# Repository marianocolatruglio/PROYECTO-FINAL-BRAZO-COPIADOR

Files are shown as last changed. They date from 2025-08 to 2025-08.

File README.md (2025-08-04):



# Sistema de Digitalizacion y Reproduccion de Contornos
Desarrollado por Colatruglio M. - Dziubek N.
## Introduccion

La evolución tecnológica en el ámbito industrial ha llevado a una creciente necesidad de soluciones automatizadas que permitan a pequeñas y medianas empresas mejorar su competitividad. En particular, el desarrollo de herramientas capaces de reproducir trayectorias manuales con precisión resulta de gran interés para sectores como la metalurgia, carpintería o manufactura personalizada.
La automatización industrial ha impulsado el desarrollo de dispositivos capaces de ejecutar tareas con precisión creciente. En este contexto, los brazos articulados han demostrado ser herramientas fundamentales para reproducir trayectorias definidas, tanto en entornos remotos como en talleres locales.
Este tipo de tecnología también resulta útil en talleres metalúrgicos de pequeña escala, donde un operario puede escanear una pieza irregular guiando manualmente el brazo y luego reproducir la misma trayectoria para realizar cortes sobre placas de metal. Esto permite fabricar tanto piezas únicas como series reducidas de forma eficiente.
Frente a la necesidad de una alternativa nacional y de bajo costo a los sistemas importados, se desarrolló un prototipo funcional que demuestra la viabilidad técnica de capturar y reproducir trayectorias con buena precisión, empleando componentes accesibles como Arduino y piezas impresas en 3D.
El proyecto consistió en desarrollar un brazo articulado de dos grados de libertad, capaz de grabar trayectorias guiadas por el usuario y luego reproducirlas automáticamente. Este tipo de soluciones se observa en la industria metalúrgica internacional, especialmente en tareas de corte térmico.
Se planteó una alternativa local escalable, partiendo de un prototipo a pequeña escala como prueba de concepto. Si bien este no incluye herramientas de corte reales, sí valida el sistema de guiado, almacenamiento y reproducción.

RENDER1

# Objetivo
* Proveer a la industria de un sistema de posicionamiento robotico para operaciones de corte de metales in-situ de bajo costo , modular y de facil operacion, utilizando una estructura abierta.
* Sustituir equipos importados de alto costo.

# Principio de Funcionamiento 

Se seleccionó como accionamiento 2 motores paso a paso, por su simplicidad y presición de posicionamiento, utilizando una configuracion de multistepping 1/16. Ademas se agregaron encoders magneticos AS5600 que tienen una 
precision de 4096 steps/rev. Estos se utilizaran para obtener la posicion angular de los brazos. Con esta informacion crearemos un streaming de datos se transmitirá via serial mediante pares de coordenadas que se almacenaran en un archivo .TXT a traves de un script de Python. 

## Arduino UNO 

## Resumen del funcionamiento

Este código controla un **brazo copiador** con dos motores paso a paso y encoders magnéticos **AS5600** (lectura multivuelta). Los puntos más relevantes:

1. **Lectura de encoders (AS5600):**

   * Se obtienen ángulos absolutos en crudo (RAW ANGLE) a través de I²C.
   * Se implementa un contador manual de vueltas para cada encoder usando un multiplexor 4051.

2. **Control de motores:**

   * Los motores paso a paso se manejan mediante drivers tipo A4988/TMC, con microstepping configurado a **1/8** (1600 pasos/rev, 0.225°/paso).
   * Se implementa un **movimiento interpolado** con velocidad constante de **45°/s**, ajustable con `speedFactor`.
   * Al finalizar un segmento, se aplica **corrección de posición** usando el feedback de los encoders (anti-drift).

3. **Homing automático:**

   * Rutina `homingSimultaneo()` para buscar finales de carrera, retroceder y re-inicializar el conteo de ángulos.

4. **Grabación y reproducción de trayectorias:**

   * **Grabación:** lee continuamente los ángulos de los encoders y los envía por puerto serie (`g`).
   * **Reproducción:** recibe una secuencia de ángulos (`INICIO_TRAYECTORIA` ... `FIN_TRAYECTORIA`) por serie y ejecuta los movimientos de forma sincronizada (`r`).
   * Comunicación con **handshake**: el Arduino responde con `RDY`, `OK` por cada segmento y `DONE` al finalizar.

5. **Comandos por serie:**

   * `h`: homing
   * `g`: iniciar grabación
   * `r`: reproducir trayectoria
   * `x`: detener grabación
   * `p`: imprimir posición actual
   * `e` / `d`: habilitar o deshabilitar drivers

6. **GUI - INTERFAZ GRAFICA**
   
   

8. **Detalles técnicos:**

   * Corrección de errores por redondeo en pasos mediante acumulación de restos.
   * Tiempo por paso calculado dinámicamente para mantener la velocidad angular deseada.
   * Tolerancia de corrección final de \~0.1° (medio micropaso).

## Morfologia del robot.
  Se utilizo una configuracion de brazos planos paralelos con ambos accionamientos sobre el mismo eje.
  Esto se decidió con el objetivo de reducir el peso en el extremo del robot, con el ojetivo de alcanzar extensiones largas con una inercia minima.
  La reduccion de los motores es de 88/16, mediante correas GT2, las cuales se imprimieron en 3D con filamento flexible TPU.
  De esta forma se agrupo toda la transmision en la base del dispositivo donde se concentra la mayor parte del peso.

## Encoders AS5600

Estos encoders utilizan una comunicacion I2C, con el problema que tienen una direccion estatica 0x36. lo cual nos obligo a utilizar un multiplexor, segun recomendacion del creador de la Libreria (https://github.com/RobTillaart/AS5600) utilizamos el siguiente : CD74HC4067. De esta forma podemos obtener datos de ambos encoders simultaneamente.

## CNC Shield Protoneer v3.0

La placa de expansión para máquina de grabado CNC Shield V3 de Protoneer es una placa de expansión versátil y potente diseñada para controlar motores paso a paso en máquinas CNC. Se utiliza comúnmente en routers CNC, cortadoras láser y máquinas de grabado DIY. La placa es compatible con Arduino UNO y utiliza firmware GRBL para controlar hasta cuatro motores paso a paso, lo que permite un funcionamiento preciso y eficiente de la máquina.
En nuestro proyecto la utilizamos con una configuracion personalizada para utilizar los pines disponibles para conectar los encoders, el multiplexor y los fines de carrera.

## Homing

Es necesario darle un origen de referencia al sistema, para inicializar la posicion, entonces se debio programar una rutina de homing. Utilizamos 2 microswitchs para ello, los cuales se accionan al llevar los brazos al origen.

# Componentes del Sistema 

### 🔹 Motor Paso a Paso NEMA 23

* **Descripción**: Motor paso a paso de alto torque utilizado para el control preciso de los ejes en máquinas CNC.
---

### 🔹 Placa de Expansión CNC Shield V3 para Grabado

* **Descripción**: Placa de expansión que se conecta al Arduino para controlar motores paso a paso y otros periféricos.
---

### 🔹 Fuente de Alimentación

* **Descripción**: Proporciona energía eléctrica a la CNC Shield y los componentes conectados.
---

### 🔹 Driver A4988

* **Descripción**: Controlador para motores paso a paso, utilizado para manejar los motores NEMA 23.
---

### 🔹 Arduino UNO

* **Descripción**: Microcontrolador principal que gestiona la lógica de control de la máquina CNC.
---

### 🔹 Sensor AS5600

* **Descripción**: Sensor magnético de posición rotativa, utilizado como realimentación tipo encoder.
---

### 🔹 Multiplexor CD74HC4067

* **Descripción**: Multiplexor/demultiplexor analógico de 16 canales.
---

### 🔹 Finales de Carrera (Limit Switch)

* **Descripción**: Detectan el fin de recorrido de los ejes del sistema CNC.
---

# Circuitos
circuit_image

# Fabricacion del prototipo

Para la fabricacion del prototipo utilizamos el software de modelado parametrico Solidworks, donde se modelaron integramente las piezas mecanicas, para luego ser impresas mediante el proceso de FDM.
Se utilizó una impresora Anycubic Kobra Neo 2 y las piezas se imprimieron con filamento PLA. Las correas GT2 se imprimieron con filamente FLEX - TPU.

# Prueba - VIDEO

https://github.com/user-attachments/assets/5a15703d-f460-4125-8f47-778ed20e3b36

# Despiece - VIDEO

https://github.com/user-attachments/assets/c534c029-4edf-490a-99b5-7e7f0a055c2a

# Vistas del Modelo

<p align="center">
  
</p>

<p align="center">
  
</p>

<p align="center">
  
</p>

# 🗓️ Cronograma Mensual del Proyecto Final (Marzo–Julio 2025)

| Mes | Investigación (h) | Aplicación (h) | Programación (h) | Total mensual (h) | Actividades principales |
|---|---|---|---|---|---|
| March 2025 | 1.6 | 4.7 | 4.2 | 10.5 | Inicio del proyecto, selección de plataforma, motores y encoders AS5600 |
| April 2025 | 1.1 | 3.4 | 3.0 | 7.5 | Implementación multiplexor, pruebas PWM/I2C, brazo paralelo plano |
| May 2025 | 1.1 | 3.4 | 3.0 | 7.5 | Homing, control lazo cerrado, sincronización motores |
| June 2025 | 1.1 | 3.4 | 3.0 | 7.5 | Grabación de trayectorias, visualización en Python, debugging |
| July 2025 | 3.4 | 10.1 | 9.0 | 22.5 | Validación de cinemática , pruebas finales, afinación |

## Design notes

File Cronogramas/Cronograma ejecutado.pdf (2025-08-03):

Proyecto Final | Leyenda:

## Colatruglio - Dziubek

Fecha de inicio del proyecto: | 7/4/2025 | abril | mayo | junio
7 | 8 | 9 | 10 | 11 | 12 | 13 | 14 | 15 | 16 | 17 | 18 | 19 | 20 | 21 | 22 | 23 | 24 | 25 | 26 | 27 | 28 | 29 | 30 | 1 | 2 | 3 | 4 | 5 | 6 | 7 | 8 | 9 | 10 | 11 | 12 | 13 | 14 | 15 | 16 | 17 | 18 | 19 | 20 | 21 | 22 | 23 | 24 | 25 | 26 | 27 | 28 | 29 | 30 | 31 | 1 | 2 | 3 | 4 | 5 | 6 | 7 | 8 | 9 | 10 | 11
Nº Act Descripción del hito | Categoría | Asignado a | Dependencia | Inicio | Días | l | m | m | j | v | s | d | l | m | m | j | v | s | d | l | m | m | j | v | s | d | l | m | m | j | v | s | d | l | m | m | j | v | s | d | l | m | m | j | v | s | d | l | m | m | j | v | s | d | l | m | m | j | v | s | d | l | m | m | j | v | s | d | l | m | m
1 | Modelado | Según lo previsto | Colatruglio - Dziubek | - | 7/4/2025 | 2
2 | Definición de Requerimientos | Riesgo medio | Colatruglio - Dziubek | - | 7/4/2025 | 2
3 | Definición de Lenguaje | Según lo previsto | Colatruglio - Dziubek | 2 | 9/4/2025 | 3
4 | Selección de periféricos | Riesgo medio | Colatruglio | 3 | 10/4/2025 | 4
5 | Dimensionamiento | Riesgo bajo | Colatruglio - Dziubek | 1 | 10/4/2025 | 5
6 | Gestion de Compras | Riesgo medio | Colatruglio - Dziubek | 4 | 15/4/2025 | 2
7 | Prefabricación | Según lo previsto | Colatruglio | 4 y 5 | 15/4/2025 | 4
8 | Fabricación | Según lo previsto | Colatruglio - Dziubek | 6 | 22/4/2025 | 7
9 | T. Levantamiento de Datos | Hito | Dziubek | 6 | 22/4/2025 | 1
10 | T. Giro de Motores | Riesgo medio | Colatruglio | 6 | 22/4/2025 | 4
11 | Comunicación de Periféricos | Según lo previsto | Colatruglio - Dziubek | 7 | 29/4/2025 | 4
12 | Levantamiento de Datos | Riesgo alto | Colatruglio - Dziubek | 11 | 1/5/2025 | 4
13 | T. Comunicación de periféricos | Hito | Colatruglio | 11 | 1/5/2025 | 1
14 | T. Modelo | Riesgo bajo | Dziubek | 8 y 11 | 1/5/2025 | 5

15

Desarrollo lógico de trayectorias | Riesgo medio | Colatruglio - Dziubek | 12 | 6/5/2025 | 10

16

T. Parametrización de la
información | Según lo previsto | Dziubek | 12 | 6/5/2025 | 2
17 | T. Lectura de los Sensores | Hito | Colatruglio | 12 | 6/5/2025 | 1
18 | Testeo | Riesgo alto | Colatruglio - Dziubek | 14 y 15 | 13/5/2025 | 29
19 | Corrección de errores | Según lo previsto | Colatruglio - Dziubek | 18 | 6/6/2025 | 5
20 | Puesta en Marcha | Hito | Colatruglio - Dziubek | 19 | 11/6/2025 | 1
Riesgo alto | Sin asignar

# Sistema de Digitalizacion y Reproduccion de Contornos

Según lo previsto | Riesgo bajo | Riesgo medio

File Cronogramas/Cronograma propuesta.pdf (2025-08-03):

Proyecto Final | Leyenda:

## Colatruglio - Dziubek

Fecha de inicio del proyecto: 7/4/2025 | abril | mayo | junio
7 | 8 | 9 | 10 | 11 | 12 | 13 | 14 | 15 | 16 | 17 | 18 | 19 | 20 | 21 | 22 | 23 | 24 | 25 | 26 | 27 | 28 | 29 | 30 | 1 | 2 | 3 | 4 | 5 | 6 | 7 | 8 | 9 | 10 | 11 | 12 | 13 | 14 | 15 | 16 | 17 | 18 | 19 | 20 | 21 | 22 | 23 | 24 | 25 | 26 | 27 | 28 | 29 | 30 | 31 | 1 | 2 | 3 | 4 | 5 | 6 | 7 | 8 | 9 | 10 | 11
Nº Act | Descripción del hito | Categoría | Asignado a | Dependencia | Inicio | Días | l | m | m | j | v | s | d | l | m | m | j | v | s | d | l | m | m | j | v | s | d | l | m | m | j | v | s | d | l | m | m | j | v | s | d | l | m | m | j | v | s | d | l | m | m | j | v | s | d | l | m | m | j | v | s | d | l | m | m | j | v | s | d | l | m | m
1 | Modelado | Según lo previsto | Colatruglio - Dziubek | - | 7/4/2025 | 2
2 | Definición de Requerimientos | Según lo previsto | Colatruglio - Dziubek | - | 7/4/2025 | 1
3 | Definición de Lenguaje | Según lo previsto | Colatruglio - Dziubek | 2 | 9/4/2025 | 1
4 | Selección de periféricos | Según lo previsto | Colatruglio | 3 | 10/4/2025 | 4
5 | Dimensionamiento | Según lo previsto | Colatruglio - Dziubek | 1 | 10/4/2025 | 1
6 | Gestion de Compras | Según lo previsto | Colatruglio - Dziubek | 4 | 15/4/2025 | 6
7 | Prefabricación | Según lo previsto | Colatruglio | 4 y 5 | 15/4/2025 | 1
8 | Fabricación | Según lo previsto | Colatruglio - Dziubek | 6 | 22/4/2025 | 6
9 | T. Levantamiento de Datos | Hito | Dziubek | 6 | 22/4/2025 | 1
10 | T. Giro de Motores | Según lo previsto | Colatruglio | 6 | 22/4/2025 | 1
11 | Comunicación de Periféricos | Según lo previsto | Colatruglio - Dziubek | 7 | 29/4/2025 | 1
12 | Levantamiento de Datos | Según lo previsto | Colatruglio - Dziubek | 11 | 1/5/2025 | 4
13 | T. Comunicación de periféricos | Hito | Colatruglio | 11 | 1/5/2025 | 1
14 | T. Modelo | Según lo previsto | Dziubek | 8 y 11 | 1/5/2025 | 4
15 | Desarrollo lógico de trayectorias | Según lo previsto | Colatruglio - Dziubek | 12 | 6/5/2025 | 6

16

T. Parametrización de la
| información | Según lo previsto | Dziubek | 12 | 6/5/2025 | 1
17 | T. Lectura de los Sensores | Hito | Colatruglio | 12 | 6/5/2025 | 1
18 | Testeo | Según lo previsto | Colatruglio - Dziubek | 14 y 15 | 13/5/2025 | 23
19 | Corrección de errores | Según lo previsto | Colatruglio - Dziubek | 18 | 6/6/2025 | 4
20 | Puesta en Marcha | Hito | Colatruglio - Dziubek | 19 | 11/6/2025 | 1
Riesgo alto | Sin asignar

# Sistema de Digitalizacion y Reproduccion de Contornos

Según lo previsto | Riesgo bajo | Riesgo medio

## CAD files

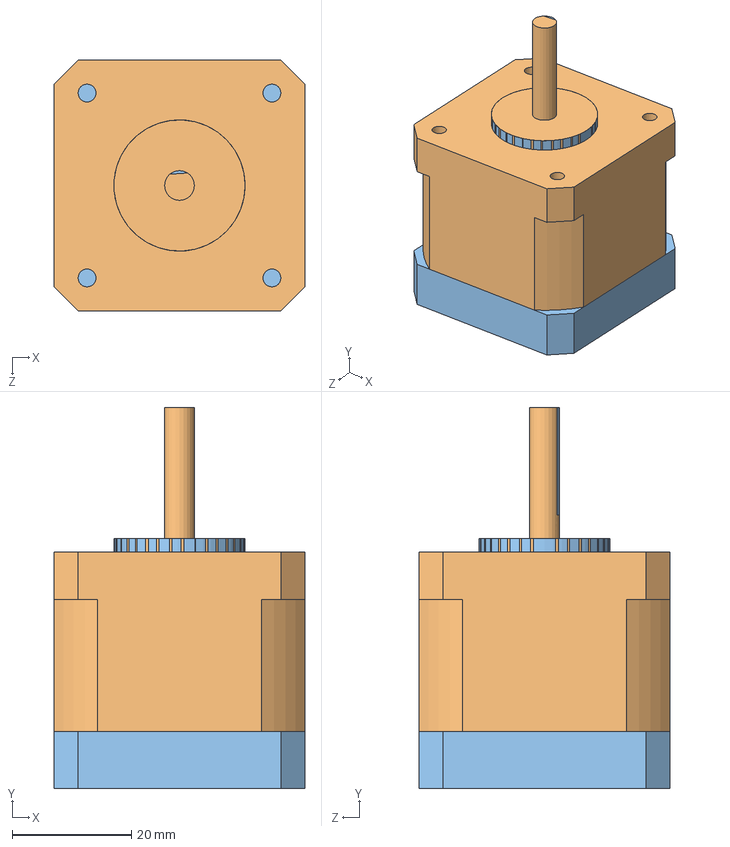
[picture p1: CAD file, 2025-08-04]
Assembly/NEMA17.SLDASM
42.0 x 63.9 x 42.0 mm

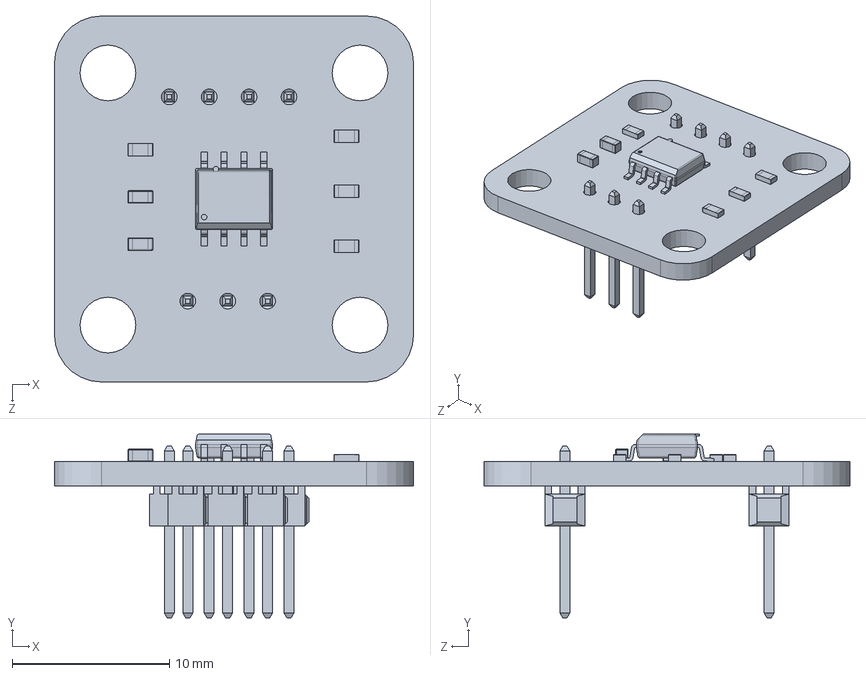
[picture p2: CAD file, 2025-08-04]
Assembly/AS5600.SLDPRT
22.9 x 11.7 x 23.3 mm

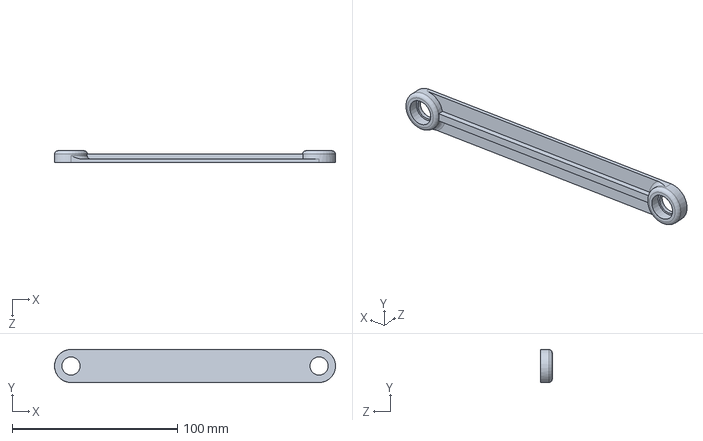
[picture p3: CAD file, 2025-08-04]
Assembly/ESLABON_3.sldprt
169.9 x 20.0 x 7.00 mm

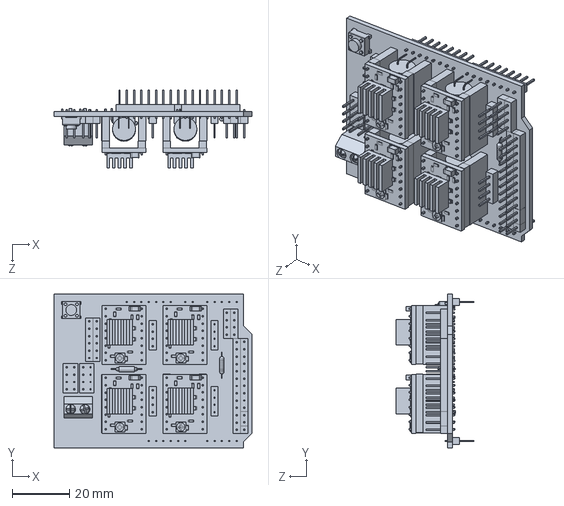
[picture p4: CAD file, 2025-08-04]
Assembly/Arduino_Uno_CNC_Shield_V3.SLDPRT
69.0 x 53.5 x 27.1 mm

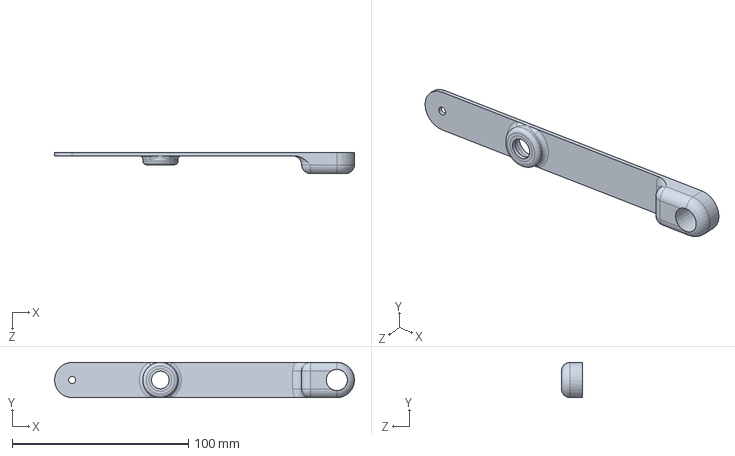
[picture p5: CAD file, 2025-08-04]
Assembly/ESLABON_4.sldprt
170.0 x 20.0 x 12.0 mm

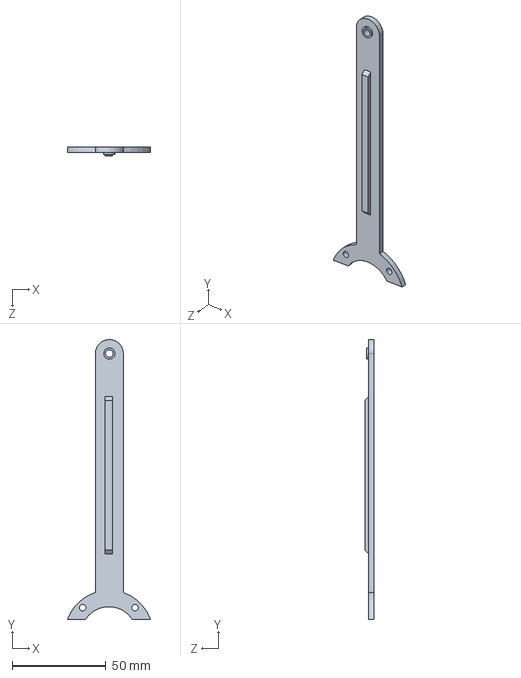
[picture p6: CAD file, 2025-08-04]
Assembly/ESLABON_1.sldprt
44.4 x 149.5 x 5.00 mm

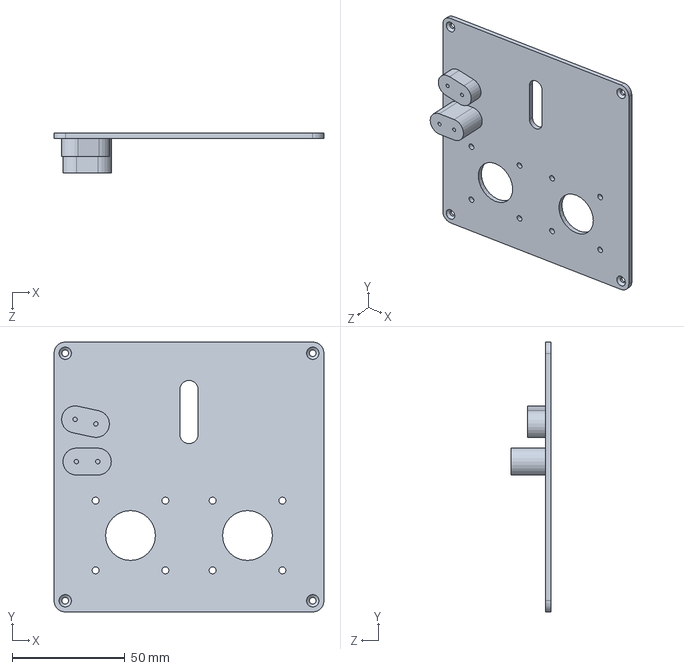
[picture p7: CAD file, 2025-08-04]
Assembly/Part5.sldprt
120.0 x 120.0 x 18.0 mm

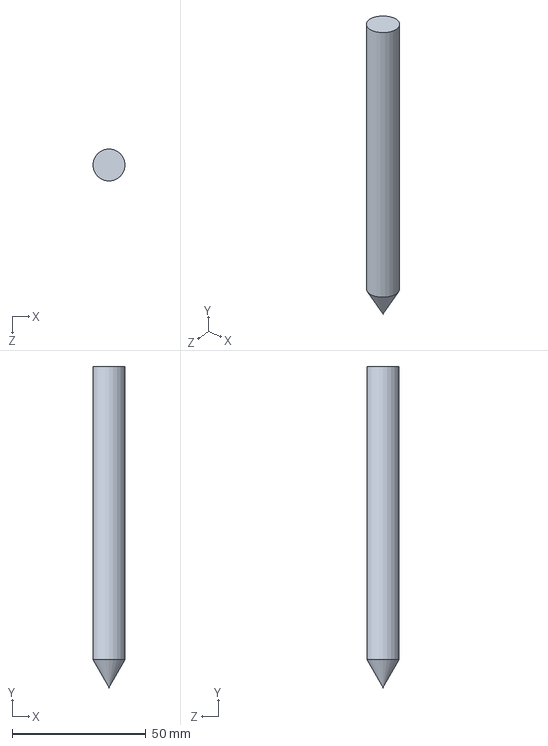
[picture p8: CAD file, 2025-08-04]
Assembly/lapiz.SLDPRT
12.0 x 120.0 x 12.0 mm

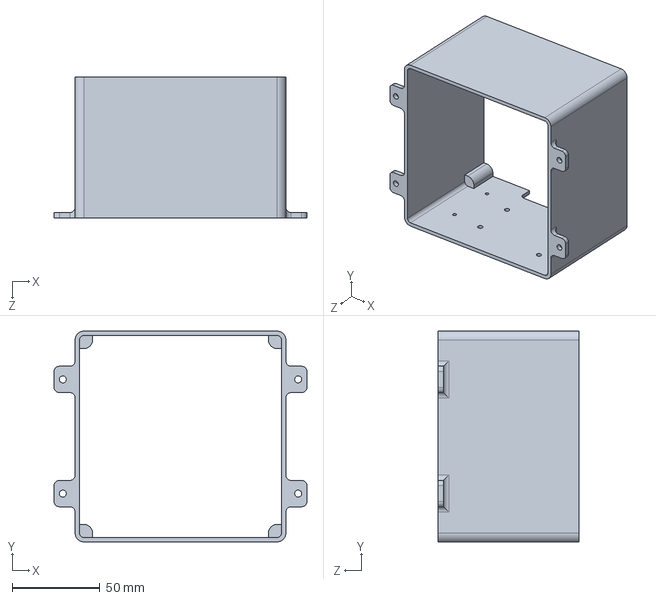
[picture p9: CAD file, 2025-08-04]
Assembly/Carcaza externa.sldprt
144.0 x 120.0 x 80.0 mm

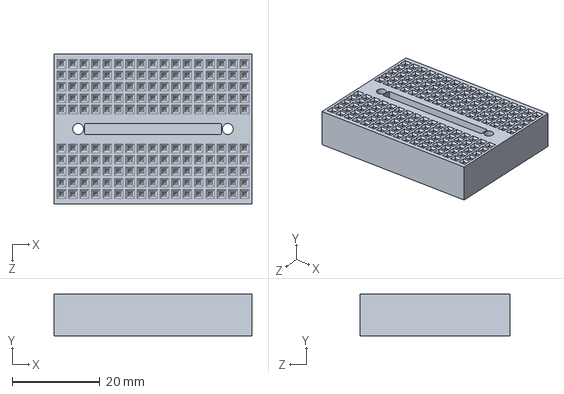
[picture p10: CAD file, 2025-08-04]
Assembly/MINIPROTOBOARD.SLDPRT
45.0 x 9.50 x 34.0 mm

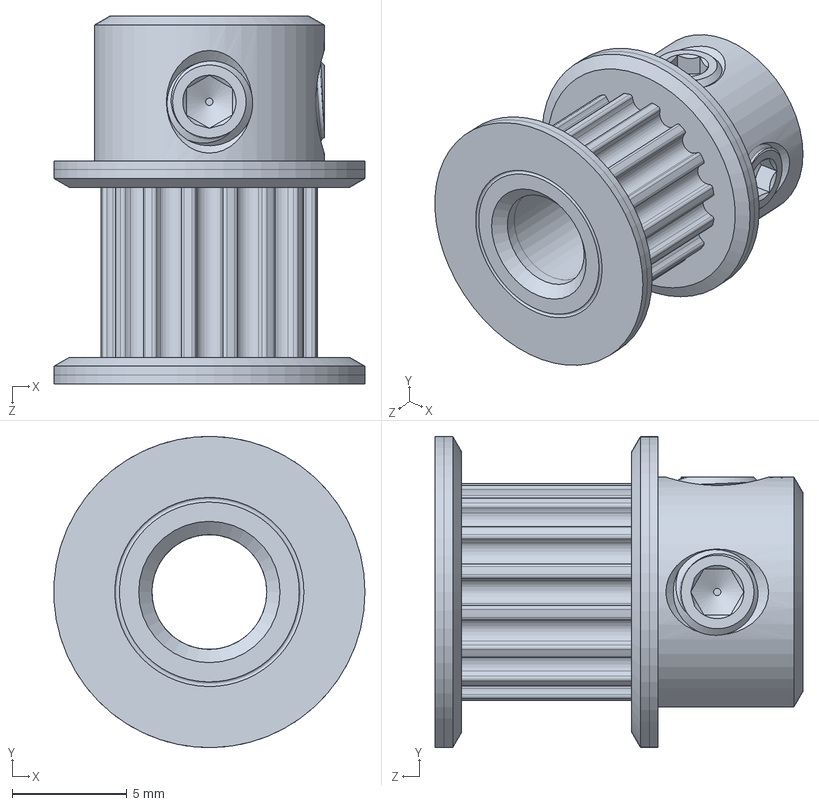
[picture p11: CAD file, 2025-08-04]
Assembly/GT2_06SWidth_16Num_5IDia_10HDia.SLDPRT
13.5 x 13.5 x 16.0 mm

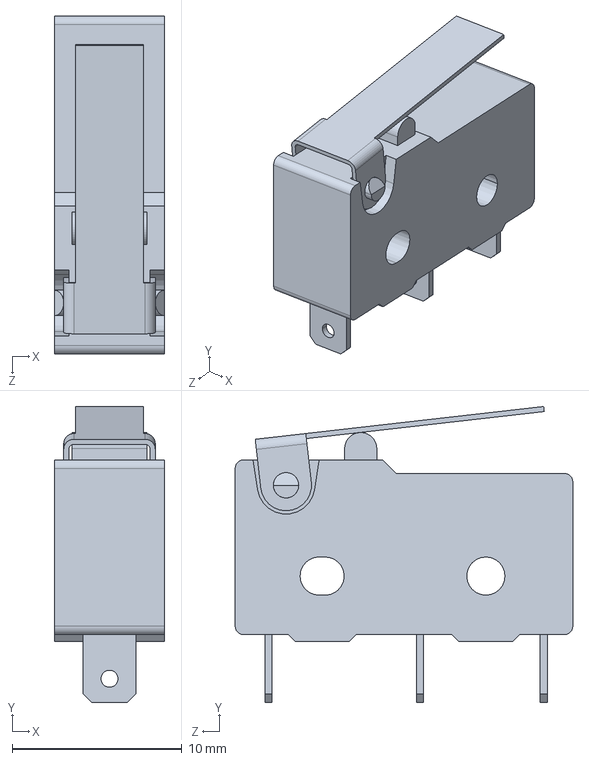
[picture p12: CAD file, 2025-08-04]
Assembly/Micro Limit Switch (Straight Lever) 605630.SLDPRT
6.50 x 17.4 x 19.9 mm

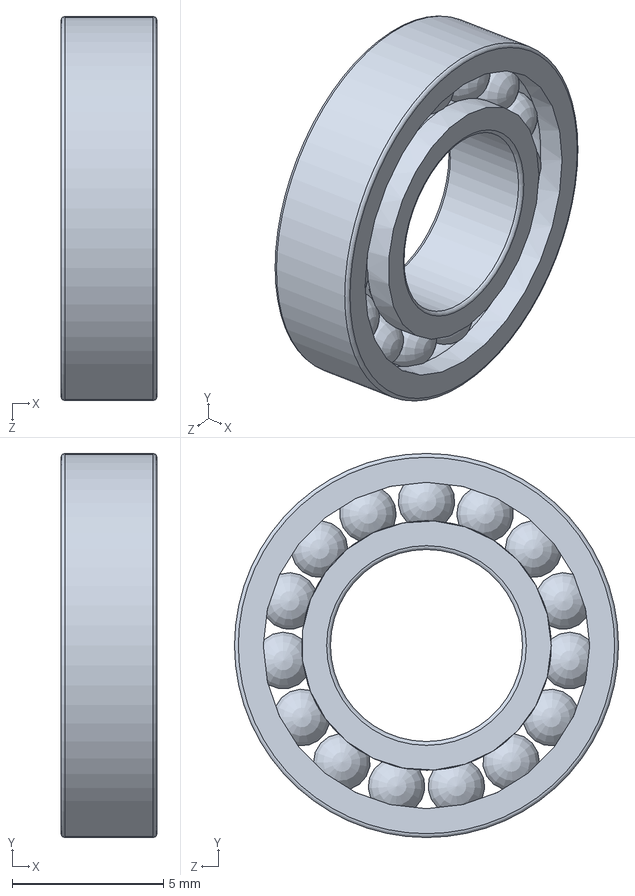
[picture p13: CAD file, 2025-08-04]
Assembly/radial ball bearing_68_skf.sldprt
3.17 x 12.7 x 12.7 mm

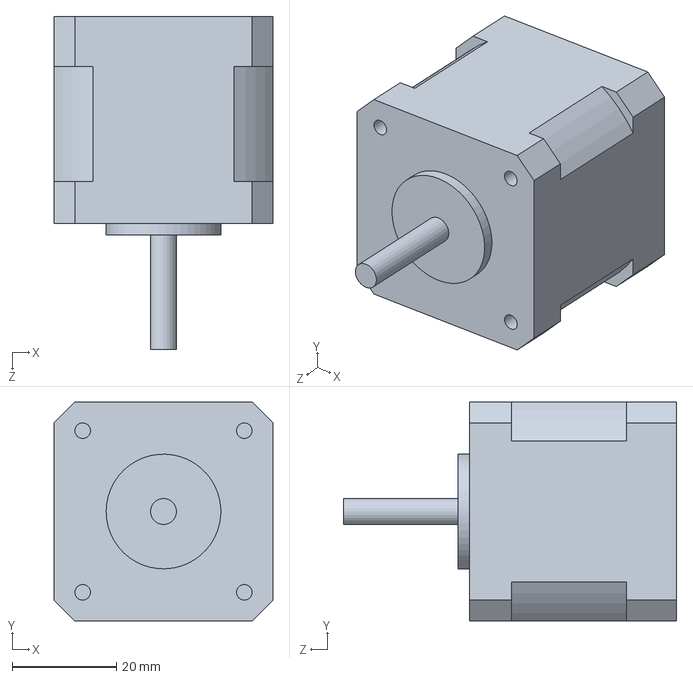
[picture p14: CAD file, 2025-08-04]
Assembly/NEMA17-SOLID.SLDPRT
42.0 x 42.0 x 63.9 mm

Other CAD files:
Assembly/Part13.sldprt
Assembly/HBOLT 0.3125-18x2x0.875-C.sldprt
Assembly/hex nut_ai.sldprt
Assembly/prevailing torque hex nut_am.sldprt
Assembly/flat washer type b narrow_ai.sldprt
Assembly/socket button head cap screw_am.sldprt

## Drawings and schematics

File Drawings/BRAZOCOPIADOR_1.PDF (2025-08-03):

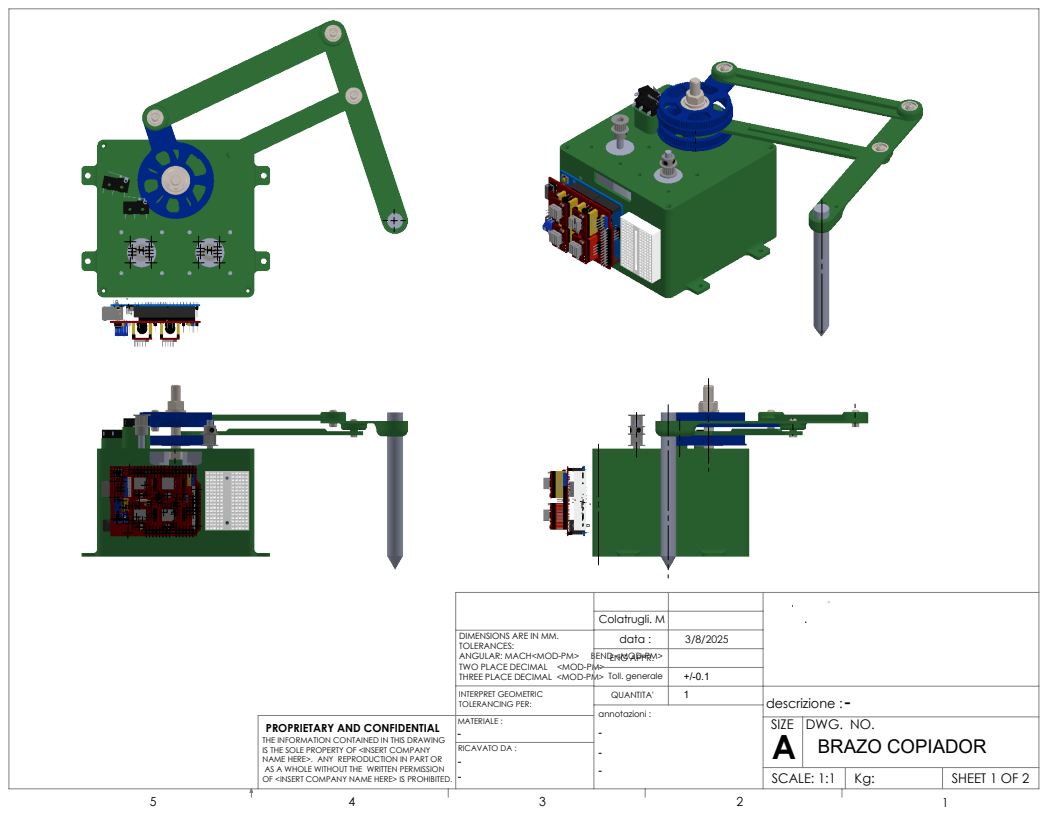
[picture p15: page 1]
BRAZO COPIADOR; SHEET 1 OF 2; Colatrugli. M; SCALE: 1:1; DWG. NO.; descrizione :; annotazioni :; Toll. generale; ENG APPR.; data :

DIMENSIONS ARE IN MM.
TOLERANCES:
ANGULAR: MACH<MOD-PM> BEND <MOD-PM>
TWO PLACE DECIMAL <MOD-PM>
THREE PLACE DECIMAL <MOD-PM>
INTERPRET GEOMETRIC
TOLERANCING PER:
MATERIALE :
RICAVATO DA :

PROPRIETARY AND CONFIDENTIAL
THE INFORMATION CONTAINED IN THIS DRAWING
IS THE SOLE PROPERTY OF <INSERT COMPANY
NAME HERE>. ANY REPRODUCTION IN PART OR
AS A WHOLE WITHOUT THE WRITTEN PERMISSION
OF <INSERT COMPANY NAME HERE> IS PROHIBITED.

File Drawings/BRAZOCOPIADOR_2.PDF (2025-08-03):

1

B

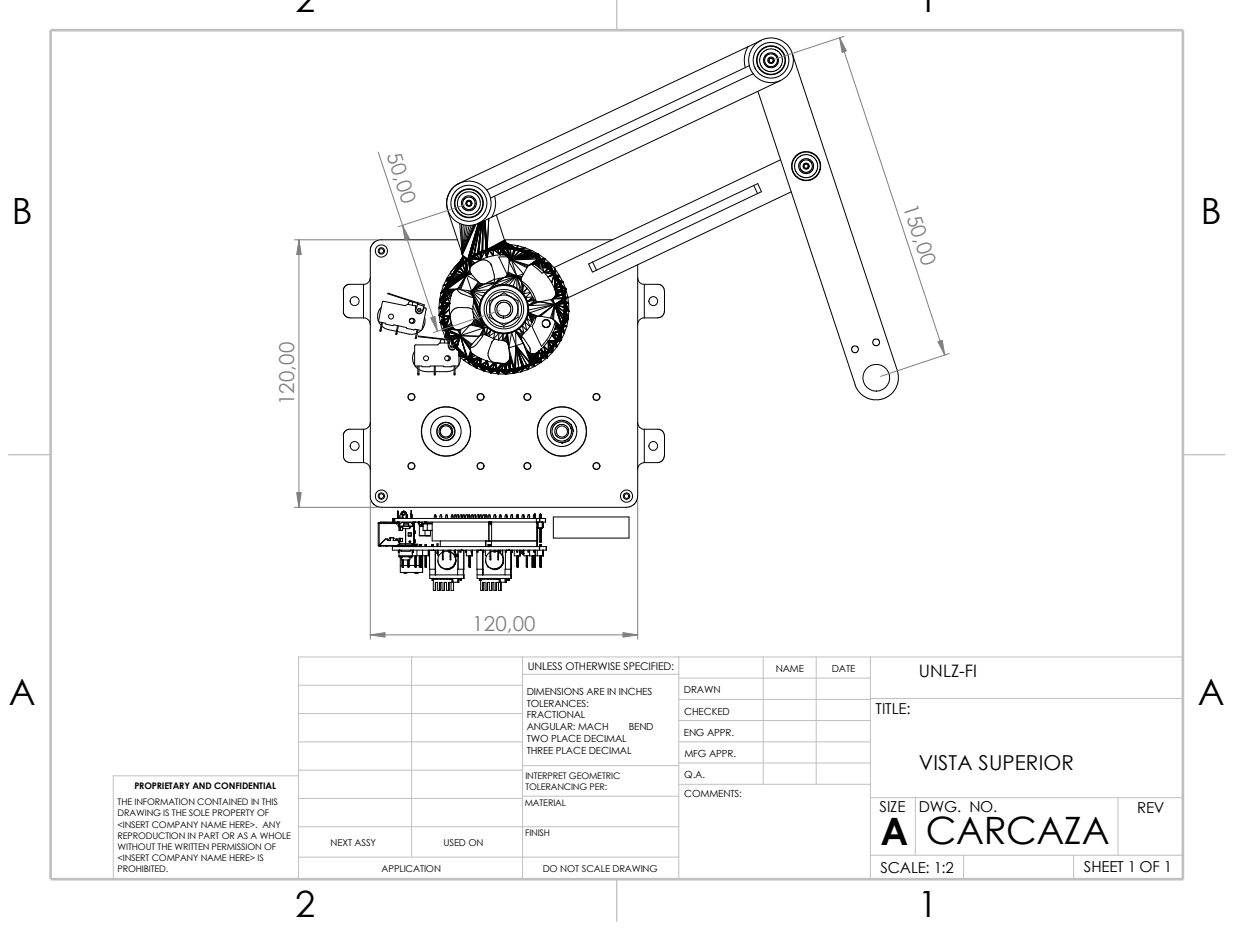
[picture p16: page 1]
COMMENTS:

NAME | DATE | UNLZ-FI UNLESS OTHERWISE SPECIFIED:

DIMENSIONS ARE IN INCHES TOLERANCES: FRACTIONAL ANGULAR: MACH BEND TWO PLACE DECIMAL THREE PLACE DECIMAL | DRAWN

CHECKED | | | TITLE: VISTA SUPERIOR

ENG APPR.
MFG APPR.

INTERPRET GEOMETRIC TOLERANCING PER: | Q.A.
MATERIAL | | SIZE A | DWG. NO. CARCAZA | REV

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

NEXT ASSY | USED ON | FINISH

APPLICATION | DO NOT SCALE DRAWING | | SCALE: 1:2 | | SHEET 1 OF 1

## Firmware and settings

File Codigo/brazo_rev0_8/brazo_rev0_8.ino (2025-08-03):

// ----------------------------------------------------------------
//  Proyecto Brazo Copiador con AS5600L multi-vuelta
//  - Lectura RAW ANGLE por I2C (registros 0x0C/0x0D)
//  - Conteo multivuelta manual por canal (con multiplexor)
//  - Reproducción por serie con handshake: RDY / OK / DONE
//  - Los ángulos recibidos/guardados son de MOTOR (no aplicar relación)
//  - Velocidad constante objetivo: 45 deg/s
//  - Microstepping: 1/8  -> PASOS_REV = 1600  (0.225°/paso)
//  - Anti-drift: acumulación de resto de pasos + corrección final con encoder
// ----------------------------------------------------------------

#include <Wire.h>
#include "AS5600.h"
#include <string.h>
#include <stdlib.h>
#include <math.h>

// Dirección I2C del AS5600
#define AS5600_ADDR 0x36

// Registros RAW ANGLE (12 bits)
#define RAW1_REG 0x0C  // MSB (bits 11:8)
#define RAW2_REG 0x0D  // LSB (bits 7:0)

// Pines de conexión motor y enable
#define STEP1       2
#define DIR1        5
#define STEP2       3
#define DIR2        6
#define ENABLE_PIN  8   // Activo en LOW en A4988/TMC típicos

// Pines multiplexor (4051)
#define S0 7           // S1/S2 cableadas según tu diseño (si no se usan, a GND/VCC fijas)

// Canales multiplexor
#define CH_ENCODER1  0
#define CH_ENCODER2  1
#define NUM_ENCODERS 2

// Pines finales de carrera
#define LIMIT1_PIN 10
#define LIMIT2_PIN  9

// ---------------------- Parámetros de movimiento -----------------
// Microstepping 1/8  -> 200 * 8 = 1600 pasos/rev
#define PASOS_REV           1600
#define V_DEG_S             45.0f   // velocidad angular objetivo (deg/s)
#define VELOCIDAD_HOMING    3000    // µs entre pasos en homing
#define RETROCESO_HOMING    22
#define DELAY_INTERPOLADO   50      // (no se usa en modo vel. constante)

// Derivados (se calculan en setup)
static float   STEP_ANGLE_DEG   = 360.0f / PASOS_REV;   // 0.225°
static uint32_t MICROS_POR_PASO = 5000UL;               // ~5 ms por paso para 45°/s

// Escalado runtime (1.0 = 45°/s; 2.0 = 90°/s; 0.5 = 22.5°/s)
float  speedFactor = 1.0f;

AS5600 as5600;
volatile bool detenerGrabacion = false;

// --------------------- Estado multivuelta manual -----------------
int32_t  cum[NUM_ENCODERS]     = {0, 0};
uint16_t prevRaw[NUM_ENCODERS] = {0, 0};

// ---------------- Acumulación de resto (anti-redondeo) -----------
static float resto1 = 0.0f, resto2 = 0.0f;
static const float TOL = 0.45f * (360.0f / PASOS_REV);  // ~0.101°: ~½ micro-paso

long pasosDesdeDeltaConResto(float delta_deg, float &resto) {
  float stepsF = delta_deg / STEP_ANGLE_DEG + resto; // = delta_deg * PASOS_REV / 360
  long  steps  = lroundf(stepsF);
  resto = stepsF - (float)steps;                      // guarda resto p/ próximo segmento
  return steps;
}

// ------------------------ Multiplexor ----------------------------
void setCanalMultiplexor(int canal) {
  digitalWrite(S0, canal & 1);
  // Si tuvieras S1/S2: digitalWrite(S1,(canal>>1)&1); digitalWrite(S2,(canal>>2)&1);
  delayMicroseconds(100);
}

// -------------------------- Encoders -----------------------------
uint16_t getRaw(int canal) {
  setCanalMultiplexor(canal);
  delay(1);  // estabilizar línea

  Wire.beginTransmission(AS5600_ADDR);
  Wire.write(RAW1_REG);
  Wire.endTransmission(false);              // mantener el bus
  Wire.requestFrom(AS5600_ADDR, 2);
  while (Wire.available() < 2);
  uint8_t msb = Wire.read();
  uint8_t lsb = Wire.read();
  return ((uint16_t(msb) << 8) | lsb) & 0x0FFF;  // 0..4095
}

float getAngleMulti(int canal) {
  uint16_t raw = getRaw(canal);
  int32_t delta = int32_t(raw) - int32_t(prevRaw[canal]);
  if (delta >  2048) delta -= 4096;   // wrap positivo
  else if (delta < -2048) delta += 4096; // wrap negativo
  cum[canal]     += delta;
  prevRaw[canal]  = raw;
  return cum[canal] * (360.0f / 4096.0f); // grados de MOTOR acumulados
}

// ------------------ Corrección de fin de segmento ----------------
void corregirEjeHasta(float tgt_deg, int ch, int stepPin, int dirPin, uint32_t dt_us) {
  for (uint16_t guard = 0; guard < 2 * PASOS_REV; guard++) {
    float err = tgt_deg - getAngleMulti(ch);
    if (fabsf(err) <= TOL) break;            // dentro de tolerancia
    bool sentido = (err > 0);
    digitalWrite(dirPin, sentido ? HIGH : LOW);
    digitalWrite(stepPin, HIGH); delayMicroseconds(10);
    digitalWrite(stepPin, LOW);  delayMicroseconds(dt_us);
  }
}

// --------------------------- Movimiento --------------------------
void moverInterpolado(float a1_ini, float a2_ini, float a1_fin, float a2_fin, int /*delay_ms*/) {
  long pasos1 = pasosDesdeDeltaConResto(a1_fin - a1_ini, resto1);
  long pasos2 = pasosDesdeDeltaConResto(a2_fin - a2_ini, resto2);

  digitalWrite(DIR1, pasos1 >= 0 ? HIGH : LOW);
  digitalWrite(DIR2, pasos2 >= 0 ? HIGH : LOW);

  pasos1 = labs(pasos1);
  pasos2 = labs(pasos2);
  long maxPasos = (pasos1 > pasos2) ? pasos1 : pasos2;
  if (maxPasos == 0) return;

  // dt ajustado por speedFactor
  uint32_t dt = (uint32_t)( (float)MICROS_POR_PASO / (speedFactor > 0 ? speedFactor : 1.0f) );

  long err1 = 0, err2 = 0;
  for (long i = 0; i < maxPasos; i++) {
    err1 += pasos1;
    if (err1 >= maxPasos) {
      digitalWrite(STEP1, HIGH); delayMicroseconds(10);
      digitalWrite(STEP1, LOW);  err1 -= maxPasos;
    }
    err2 += pasos2;
    if (err2 >= maxPasos) {
      digitalWrite(STEP2, HIGH); delayMicroseconds(10);
      digitalWrite(STEP2, LOW);  err2 -= maxPasos;
    }
    delayMicroseconds(dt);
  }

  // Corrección final guiada por encoder para aterrizar sobre el objetivo
  corregirEjeHasta(a1_fin, CH_ENCODER1, STEP1, DIR1, dt);
  corregirEjeHasta(a2_fin, CH_ENCODER2, STEP2, DIR2, dt);
}

// ---------------------------- Homing -----------------------------
void moverPaso(int stepPin, int dirPin, bool sentido, int pasos, int delay_us) {
  digitalWrite(dirPin, sentido ? HIGH : LOW);
  for (int i = 0; i < pasos; i++) {
    digitalWrite(stepPin, HIGH);
    delayMicroseconds(10);
    digitalWrite(stepPin, LOW);
    delayMicroseconds((uint32_t)delay_us);
  }
}

void homingSimultaneo() {
  digitalWrite(ENABLE_PIN, LOW); // activar drivers
  Serial.println("Iniciando homing...");

  pinMode(LIMIT1_PIN, INPUT_PULLUP);
  pinMode(LIMIT2_PIN, INPUT_PULLUP);
  digitalWrite(DIR1, LOW);
  digitalWrite(DIR2, LOW);

  bool listo1 = false, listo2 = false;
  while (!listo1 || !listo2) {
    if (!listo1 && digitalRead(LIMIT1_PIN)) {
      digitalWrite(STEP1, HIGH); delayMicroseconds(10);
      digitalWrite(STEP1, LOW);  delayMicroseconds((uint32_t)VELOCIDAD_HOMING);
    } else listo1 = true;

    if (!listo2 && digitalRead(LIMIT2_PIN)) {
      digitalWrite(STEP2, HIGH); delayMicroseconds(10);
      digitalWrite(STEP2, LOW);  delayMicroseconds((uint32_t)VELOCIDAD_HOMING);
    } else listo2 = true;
  }

  moverPaso(STEP1, DIR1, HIGH, RETROCESO_HOMING, VELOCIDAD_HOMING);
  moverPaso(STEP2, DIR2, HIGH, RETROCESO_HOMING, VELOCIDAD_HOMING);

  Serial.println("Homing completado.");

  // Re-inicializar nuestro conteo manual
  for (int ch = 0; ch < NUM_ENCODERS; ch++) {
    prevRaw[ch] = getRaw(ch);
    cum[ch]     = 0;
  }

  // Reset de restos para reproducción limpia
  resto1 = resto2 = 0.0f;
}

// --------------- Recepción y reproducción (con handshake) --------
void recibirYReproducirSerial() {
  // Limpiar residuo y anunciar disponibilidad
  while (Serial.available()) Serial.read();
  Serial.println("RDY");

  bool reproduciendo = false;
  const int BUF = 48;
  char buf[BUF];

  float a1_ant = getAngleMulti(CH_ENCODER1);
  float a2_ant = getAngleMulti(CH_ENCODER2);

  // reset de restos al iniciar una reproducción
  resto1 = resto2 = 0.0f;

  uint32_t t0 = millis();
  const uint32_t TO = 30000; // 30 s

  for (;;) {
    if (millis() - t0 > TO) break;

    int len = Serial.readBytesUntil('\n', buf, BUF - 1);
    if (len <= 0) { delay(1); continue; }
    buf[len] = '\0';
    if (len > 0 && buf[len - 1] == '\r') buf[len - 1] = '\0';

    t0 = millis();

    if (!reproduciendo) {
      if (strcmp(buf, "INICIO_TRAYECTORIA") == 0) reproduciendo = true;
      continue;
    }

    if (strcmp(buf, "FIN_TRAYECTORIA") == 0) {
      Serial.println("DONE");
      break;
    }

    // Parsear manual "a1,a2"
    char *comma = strchr(buf, ',');
    if (comma) {
      *comma = '\0';
      float a1 = atof(buf);
      float a2 = atof(comma + 1);
      moverInterpolado(a1_ant, a2_ant, a1, a2, DELAY_INTERPOLADO);
      a1_ant = a1; a2_ant = a2;
      Serial.println("OK"); // ACK por segmento
    }
  }

  Serial.println("Reproducción finalizada.");
  while (Serial.available()) Serial.read();
}

// ---------------------------- Utilidades -------------------------
void grabarDesdeEncoders() {
  detenerGrabacion = false;
  Serial.println("INICIO_TRAYECTORIA");
  while (!detenerGrabacion) {
    if (Serial.available() && Serial.read() == 'x') break;
    float a1 = getAngleMulti(CH_ENCODER1);
    float a2 = getAngleMulti(CH_ENCODER2);
    Serial.print(a1); Serial.print(","); Serial.println(a2);
    delay(50);
  }
  Serial.println("FIN_TRAYECTORIA");
}

void printPosition() {
  float p1 = getAngleMulti(CH_ENCODER1);
  float p2 = getAngleMulti(CH_ENCODER2);
  Serial.print(p1, 2); Serial.print(","); Serial.println(p2, 2);
}

// ------------------------------ Setup/Loop -----------------------
void setup() {
  Serial.begin(115200);
  Serial.setTimeout(50); // para readBytesUntil

  Wire.begin();
  as5600.begin();
  as5600.setDirection(AS5600_CLOCK_WISE);
  as5600.resetPosition();

  pinMode(STEP1, OUTPUT); pinMode(DIR1, OUTPUT);
  pinMode(STEP2, OUTPUT); pinMode(DIR2, OUTPUT);
  pinMode(ENABLE_PIN, OUTPUT);  digitalWrite(ENABLE_PIN, LOW); // habilitar
  pinMode(S0, OUTPUT);

  // Inicializar acumuladores
  for (int ch = 0; ch < NUM_ENCODERS; ch++) {
    prevRaw[ch] = getRaw(ch);
    cum[ch]     = 0;
  }

  // Calcular parámetros de velocidad (1/8 microstep, 45°/s)
  STEP_ANGLE_DEG   = 360.0f / PASOS_REV;                  // 0.225°
  MICROS_POR_PASO  = (uint32_t)((360.0f * 1000000.0f) / (PASOS_REV * V_DEG_S)); // ~5000 µs

  Serial.print("STEP_ANGLE_DEG= "); Serial.println(STEP_ANGLE_DEG, 6);
  Serial.print("MICROS_POR_PASO= "); Serial.println(MICROS_POR_PASO);
  Serial.println("Listo. Esperando comando...");
}

void loop() {
  if (!Serial.available()) return;
  char c = Serial.read();
  if      (c == 'h') homingSimultaneo();
  else if (c == 'r') recibirYReproducirSerial();
  else if (c == 'g') grabarDesdeEncoders();
  else if (c == 'x') detenerGrabacion = true;
  else if (c == 'e') digitalWrite(ENABLE_PIN, LOW);
  else if (c == 'd') digitalWrite(ENABLE_PIN, HIGH);
  else if (c == 'p') printPosition();
}

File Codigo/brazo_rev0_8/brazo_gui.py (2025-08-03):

import tkinter as tk
from tkinter import filedialog, messagebox
import serial
import threading
import time

class BrazoCopiadorApp:
    def __init__(self, master):
        self.master = master
        master.title("Brazo Copiador - Grabación y Reproducción")

        self.serial_port = tk.StringVar(value="COM6")
        self.baudrate = 115200
        self.ser = None

        # Config del sistema mecánico
        self.PASOS_REV = 1600              # 1/8 microstepping
        self.STEP_ANGLE = 360.0 / self.PASOS_REV  # 0.225°/paso

        # Variable UI
        self.current_pos = tk.StringVar(value="---")
        self.quantize_var = tk.BooleanVar(value=False)  # cuantizar a resolución de paso

        self.build_gui()

    def build_gui(self):
        frame = tk.Frame(self.master)
        frame.pack(padx=20, pady=20)

        # Conexión
        tk.Label(frame, text="Puerto Serial:").grid(row=0, column=0)
        tk.Entry(frame, textvariable=self.serial_port, width=10).grid(row=0, column=1)
        tk.Button(frame, text="Conectar", command=self.conectar).grid(row=0, column=2)

        # Acciones principales
        tk.Button(frame, text="Grabar trayectoria", command=self.grabar_trayectoria).grid(row=1, column=0, columnspan=3, pady=2)
        tk.Button(frame, text="Reproducir trayectoria", command=self.reproducir_trayectoria).grid(row=2, column=0, columnspan=3, pady=2)
        tk.Button(frame, text="Hacer Homing", command=self.enviar_homing).grid(row=3, column=0, columnspan=3, pady=2)
        tk.Button(frame, text="Enable", command=self.toggle_enable).grid(row=4, column=0, pady=2)
        tk.Button(frame, text="Disable", command=self.toggle_disable).grid(row=4, column=1, pady=2)
        tk.Button(frame, text="Detener Grabación", command=self.detener_grabacion).grid(row=5, column=0, columnspan=3, pady=2)

        # Opciones
        tk.Checkbutton(frame, text="Cuantizar a paso (0.225°)", variable=self.quantize_var).grid(row=6, column=0, columnspan=2, sticky="w")

        # Posición actual
        tk.Label(frame, text="Posición Actual (°):").grid(row=7, column=0)
        tk.Label(frame, textvariable=self.current_pos, width=14, relief="sunken").grid(row=7, column=1)
        tk.Button(frame, text="Actualizar posición", command=self.mostrar_posicion).grid(row=7, column=2, pady=2)

    # ------------------------ Helpers serial ---------------------
    def conectar(self):
        try:
            self.ser = serial.Serial(self.serial_port.get(), self.baudrate, timeout=1)
            time.sleep(2)
            messagebox.showinfo("Conectado", f"Conectado a {self.serial_port.get()}")
        except Exception as e:
            messagebox.showerror("Error de conexión", str(e))

    def _wait_for(self, token: str, timeout=5.0) -> bool:
        t0 = time.time()
        while time.time() - t0 < timeout:
            raw = self.ser.readline()
            if not raw:
                continue
            line = raw.decode(errors="ignore").strip()
            if token in line:
                return True
        return False

    # ------------------------ Grabación --------------------------
    def grabar_trayectoria(self):
        if not self.ser:
            messagebox.showerror("Error", "Primero conectá el puerto serial.")
            return
        archivo = filedialog.asksaveasfilename(defaultextension=".csv",
                                               filetypes=[("CSV files", "*.csv")])
        if not archivo:
            return

        def grabar():
            # Preparar puerto
            self.ser.timeout = 0.8      # lectura ágil
            self.ser.reset_input_buffer()
            self.ser.write(b"g")        # pedir grabación en Arduino

            grabando = False
            last_rx = time.time()       # último paquete recibido (se resetea con cada línea)

            try:
                with open(archivo, "w") as f:
                    while True:
                        raw = self.ser.readline()  # bloquea hasta timeout (0.8 s)
                        if raw:
                            last_rx = time.time()  # llegó algo -> reseteo watchdog
                            linea = raw.decode(errors="ignore").strip()
                            if linea == "INICIO_TRAYECTORIA":
                                grabando = True
                                continue
                            if linea == "FIN_TRAYECTORIA":
                                break
                            if grabando and "," in linea:
                                try:
                                    ang1, ang2 = linea.split(",", 1)
                                    float(ang1); float(ang2)  # valida
                                    f.write(f"{ang1},{ang2}\n")
                                except ValueError:
                                    pass
                        else:
                            # No llegó nada en 'timeout'; verifico inactividad prolongada
                            if time.time() - last_rx > 3.0:  # 3 s sin datos
                                # mejor enviar 'x' para terminar polite
                                try: self.ser.write(b"x")
                                except: pass
                                # Mostramos el error en el hilo principal de Tk
                                self.master.after(0, lambda: messagebox.showerror(
                                    "Timeout",
                                    "No llegan datos del Arduino hace 3 s. ¿Está enviando 'INICIO_TRAYECTORIA' y las muestras?"))
                                return
            finally:
                # Mensaje final seguro en el hilo principal
                self.master.after(0, lambda: messagebox.showinfo("Listo", f"Trayectoria guardada en {archivo}"))

        threading.Thread(target=grabar, daemon=True).start()


    # ------------------------ Reproducción -----------------------
    def reproducir_trayectoria(self):
        if not self.ser:
            messagebox.showerror("Error", "Primero conectá el puerto serial.")
            return
        archivo = filedialog.askopenfilename(filetypes=[("CSV files", "*.csv")])
        if not archivo:
            return
        def enviar():
            self.ser.reset_input_buffer()
            self.ser.write(b"r")  # invoca recibirYReproducirSerial()
            if not self._wait_for("RDY", timeout=2.0):
                messagebox.showerror("Error", "Arduino no respondió RDY.")
                return
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

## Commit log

2025-06-24 correccion encoders
2025-06-24 alineacion y calibracion de medidas
2025-06-28 registro de posiciones en archivo
2025-08-03 Revision total
    [prueba.csv]
